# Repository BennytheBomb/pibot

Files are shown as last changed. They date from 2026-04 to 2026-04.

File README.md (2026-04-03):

# PiBot — Open Source Autonomous Indoor Robot

> A fully autonomous indoor mobile robot built on Raspberry Pi 5, featuring SLAM-based mapping, Nav2 autonomous navigation, and a complete ROS 2 software stack. Built from scratch as a learning project and open sourced for the robotics community.

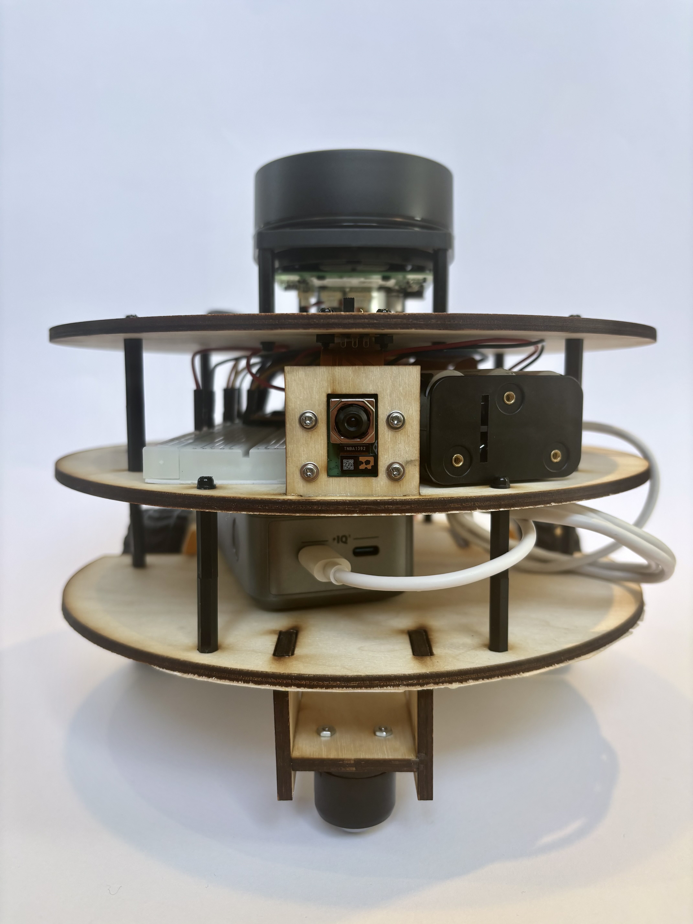
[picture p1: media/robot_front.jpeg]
PiBot Robot


---

## Table of Contents

1. [Project Overview](#1-project-overview)
2. [Design Decisions](#2-design-decisions)
3. [Bill of Materials](#3-bill-of-materials)
4. [Chassis Design and Assembly](#4-chassis-design-and-assembly)
5. [Wiring and Electronics](#5-wiring-and-electronics)
6. [Ubuntu 24.04 Setup](#6-ubuntu-2404-setup)
7. [libcamera Build from Source](#7-libcamera-build-from-source)
8. [ROS 2 Jazzy Setup](#8-ros-2-jazzy-setup)
9. [PlatformIO and Pico Firmware](#9-platformio-and-pico-firmware)
10. [ROS 2 Workspace Setup](#10-ros-2-workspace-setup)
11. [Development Tools](#11-development-tools)
12. [Calibration](#12-calibration)
13. [Running the Robot](#13-running-the-robot)
14. [SLAM Mapping](#14-slam-mapping)
15. [Autonomous Navigation with Nav2](#15-autonomous-navigation-with-nav2)
16. [Troubleshooting](#16-troubleshooting)
17. [Known Issues and Lessons Learned](#17-known-issues-and-lessons-learned)
18. [Future Work](#18-future-work)
19. [Resources](#19-resources)

---

## 1. Project Overview

PiBot is a fully autonomous indoor mobile robot built from scratch using off-the-shelf components and open source software. The project covers the complete robotics stack:

- **Hardware:** Custom laser-cut plywood chassis, differential drive with encoder motors, RPLIDAR A1, GY-87 IMU
- **Firmware:** PID velocity control on Raspberry Pi Pico 2W
- **Middleware:** ROS 2 Jazzy on Raspberry Pi 5 running Ubuntu 24.04
- **Perception:** RPLIDAR A1M8 for 2D lidar scanning
- **Localization:** AMCL on a pre-built map
- **Mapping:** SLAM Toolbox for online async mapping
- **Navigation:** Nav2 with Regulated Pure Pursuit controller
- **Sensor Fusion:** robot_localization EKF fusing wheel odometry and IMU

The project started as a ball-following robot following the [Digikey ROS 2 Tutorial Series](https://www.youtube.com/watch?v=mjrxf8EFSb8&list=PLEBQazB0HUySWueUF2zNyrA8LSX3rDvE7) and evolved into the full autonomous navigation stack in `pibot_base`.

> **Note:** The Raspberry Pi Camera Module 3 and `camera_ros` driver are included in the repository for optional use (e.g. computer vision, object detection) but are **not required** for replicating the navigation robot. The core navigation stack uses only the RPLIDAR and IMU.

**Navigation accuracy:** ~±10cm position, ~±30° heading at goal.
**Power bank runtime:** ~1 hour on the Anker Prime 12,000mAh.
**Motor battery runtime:** Varies — NiMH batteries drain faster than expected under load. Keep spare batteries charged.

### Architecture Overview

```mermaid
graph TD
    subgraph Pi5["Raspberry Pi 5 — ROS 2 Jazzy"]
        SB[serial_bridge\nodom + IMU publisher\ncmd_vel subscriber]
        EKF[robot_localization\nEKF sensor fusion]
        SLAM[SLAM Toolbox\nonline async mapping]
        NAV2[Nav2\npath planning + control]
        RSP[robot_state_publisher\nURDF + TF static]
        LIDAR[rplidar_ros\nlidar driver]
    end

    subgraph Pico["Raspberry Pi Pico 2W — bare metal"]
        PID[PID velocity control\n100Hz]
        ENC[Encoder ISR\nCHANGE interrupt]
        IMU_FW[IMU reader\nMPU6050 I2C]
    end

    subgraph Hardware["Hardware"]
        TB[TB6612FNG\nmotor driver]
        MOTORS[TT Motors ×2\nwith encoder]
        GY87[GY-87 IMU]
        RPLIDAR_HW[RPLIDAR A1M8]
    end

    Pi5 -- USB Serial\nleft_vel,right_vel --> Pico
    Pico -- USB Serial\nticks + IMU 50Hz --> Pi5

    PID --> TB --> MOTORS
    MOTORS --> ENC
    GY87 --> IMU_FW
    RPLIDAR_HW --> LIDAR

    SB --> EKF
    EKF --> SLAM
    EKF --> NAV2
    LIDAR --> SLAM
    LIDAR --> NAV2
    RSP --> SLAM
```

### Serial Communication Protocol

```
Pi 5 → Pico:  "left_vel,right_vel\n"       (float m/s, sent on cmd_vel)
Pico → Pi 5:  "lt,rt,ax,ay,az,gx,gy,gz\n" (ticks + IMU, 50Hz)
```

---

## 2. Design Decisions

### 2.1 Raspberry Pi 5 as Main Computer

The Pi 5 has sufficient CPU performance to run ROS 2, SLAM Toolbox, and Nav2 simultaneously, native USB 3.0 for reliable RPLIDAR connection, Ubuntu 24.04 support with ROS 2 Jazzy, and wide community support.

**Tradeoff:** The Pi 5 requires more power than alternatives (~5A peak), requiring a dedicated power bank.

### 2.2 Raspberry Pi Pico 2W as Hardware Bridge

Chosen following the Digikey ROS 2 Tutorial Series recommendation:

- **Real-time control:** Linux on the Pi 5 has non-deterministic scheduling. PID at 100Hz requires precise timing — the Pico runs bare metal
- **GPIO protection:** All motor and encoder connections stay on the Pico, protecting the Pi 5
- **Separation of concerns:** Clean split between high-level navigation (Pi 5) and low-level control (Pico)
- **Price:** Very cheap — the 2W variant was chosen over standard Pico because the price difference is minimal and WiFi/Bluetooth may be useful for future projects

**Known annoyance:** When firmware crashes, you cannot simply reflash. You must unplug the USB cable, hold BOOTSEL, reinsert USB (Pico appears as `RPI-RP2` drive), then flash again. This is worth knowing before you start.

### 2.3 PlatformIO over Arduino IDE

- **Remote flashing:** Compile and flash from Pi 5 over SSH — no separate computer needed
- **VS Code integration:** Same editor used for all ROS 2 development
- **Reproducible builds:** Libraries declared in `platformio.ini`
- **CLI:** `pio run --target upload` from any terminal

### 2.4 Three-Platform Laser-Cut Chassis

Before designing, all component measurements were gathered from technical drawings, datasheets, and physical measurement with calipers. Components were then laid out in Affinity Designer (top and side view) at correct scale before cutting anything.

Three circular platforms with M3 Abstandsbolzen (hex standoffs) were chosen:
- **Bottom:** Motor support structure, ball caster mount, power bank
- **Middle:** Pi 5, breadboard, Pico, motor driver, IMU
- **Top:** Lidar, camera

**Why circular:** Optimal for Nav2 — equal turning radius in all directions, simplest costmap footprint.

**Why laser-cut plywood:** Fast to iterate, precise holes, cheap, widely available at makerspaces.

**Why standoffs over spacers:** Laser-cutting spacers from acrylic would be brittle under screw torque. M3 brass standoffs are rigid, reusable, and cheap.

**Motor layout:** An equilateral triangle was designed to position motors and ball caster with equal spacing — theoretically optimal for turning. In practice the wheels stick out slightly more than planned due to not fully accounting for wheel width during layout. No operational impact but worth planning carefully.

**Kerf note:** The laser cutter removes a small amount of material (kerf) at each cut — this was not accounted for in the design. Joints that were intended to be tight fits were slightly loose as a result. Wood glue was used to compensate and produced a very stable result.

### 2.5 Wood Glue for Support Structure

The T-shaped support structure connecting motors and ball caster to the bottom platform is assembled using wood glue in addition to screws. The glue compensates for kerf tolerances and significantly increases rigidity.

### 2.6 RPLIDAR A1 over Other Lidars

Cheapest available 360° lidar at Berrybase.de (~€90). Praised by the Digikey channel for price-to-performance. 12m range and 5-8Hz scan rate are adequate for slow indoor navigation.

### 2.7 Anker Prime Power Bank

The Anker Prime 12,000mAh 130W powers the Pi 5 and all connected electronics (cooling fan, lidar, encoders, Pico). Provides ~1 hour runtime. Minimum 5V/5A output is required for stable Pi 5 operation.

### 2.8 NiMH Batteries for Motors

6× AA NiMH 1.2V 2800mAh batteries power the motors. NiMH chosen over alkaline for rechargeability and consistent voltage under load. Runtime is shorter than expected under heavy use — keep spare sets charged.

### 2.9 camera_ros for Camera Integration (Optional)

The `camera_ros` package by Christian Rauch is included in the repository for optional Camera Module 3 integration. It handles the libcamera stack natively as a ROS 2 node, publishing standard `sensor_msgs/Image` topics. This is useful for future extensions like object detection or visual servoing, but is **not required** for the core navigation stack. If you don't plan to use a camera, you can skip the libcamera build (Section 7) and ignore the `camera_ros` submodule.

---

## 3. Bill of Materials

### Electronics (Berrybase.de)

| Component | Description | Qty | Unit Price | Total |
|---|---|-----|---|---|
| Raspberry Pi 5 | 8GB RAM, main compute | 1 | €127.90 | €127.90 |
| Raspberry Pi Pico 2W | RP2350 + WiFi + BT, with headers | 1 | €8.50 | €8.50 |
| _Raspberry Pi Camera Module 3 (optional)_ | 12MP, IMX708 sensor | 1 | €28.90 | €28.90 |
| Raspberry Pi Active Cooler | Fan for Pi 5 | 1 | €5.90 | €5.90 |
| _Raspberry Pi 27W USB-C PSU (optional)_ | For desktop use / initial setup | 1 | €12.40 | €12.40 |
| Seeed RPLIDAR A1M8 | 360° 2D laser scanner, 12m range | 1 | €89.90 | €89.90 |
| DFRobot TT Motor with Encoder | 160RPM, 120:1, quadrature encoder | 2 | €7.30 | €14.60 |
| SparkFun TB6612FNG | Dual motor driver with headers | 1 | €15.90 | €15.90 |
| GY-87 IMU | MPU-6050 + HMC5883L + BMP180 | 1 | €12.80 | €12.80 |
| Pololu Ball Caster | 0.75 inch metal ball, adjustable height | 1 | €4.50 | €4.50 |
| Wheels 65mm | Rubber tyre, 2 pieces | 1 set | €4.60 | €4.60 |
| Breadboard 830 contacts | Main wiring board | 1 | €1.90 | €1.90 |
| Jumper Wire Set | F-F / M-M / F-M, 20cm | 1 | €4.90 | €4.90 |
| Battery Holder 6× AA | With 150mm cable | 2 | €0.75 | €1.50 |
| **Electronics Total** | | | | **~€333** |

> Prices from Berrybase.de, early 2026.

### Additional Components

| Component | Description | Notes |
|---|---|---|
| Anker Prime Power Bank | 12,000mAh, 130W, USB-C | Powers Pi 5 + all electronics. Minimum 5V/5A required |
| AA NiMH Batteries (6×) | 1.2V, 2800mAh per cell | Motor power. Keep spare sets charged |
| Slide switch (SPST) | Two-position slide switch | Battery power cutoff, mounted with M2.5 screws |
| 4mm birch plywood | ~30×30cm sheet | Laser cut chassis. Available at hardware stores |
| Wood glue | Standard PVA wood glue | For chassis support structure assembly |
| M2/M2.5/M3 assorted screw kit | 900-piece set | See note below |
| M3 × 30mm screws (extra) | Motor mounting | Not included in standard kits — source separately |
| M2.5 × 40mm hex standoffs | Platform spacing | 6x 40mm standoffs or 12x 20mm standoffs (screwed together) |

**Screw sizes used:**
- M2.5 × 8mm, 12mm, 20mm — Pi 5 mounting
- M2 × 6mm, 8mm, 10mm, 12mm — Camera Module 3 and small components
- M3 × 8mm, 12mm, 16mm, 20mm — General chassis mounting
- M3 × 30mm — Motor mounting (source separately from hardware store or makerspace)

**Estimated total cost: ~€380–420** including power bank, batteries, screws, plywood, and glue.

---

## 4. Chassis Design and Assembly

### 4.1 Design Process

All component measurements were gathered before designing:
- Technical drawings: Pi 5, Camera Module 3, Pico 2W datasheets
- Product descriptions: motors, lidar, ball caster
- Physical calipers: wheel diameter, motor body, connectors

Components were laid out in Affinity Designer in both top view and side view at correct scale before cutting. This step is essential — it reveals conflicts and tight fits before wasting material.

### 4.2 Platform Stack

```
Top platform    z=138.7mm   Lidar (on standoffs), camera (front)
      │
      │  40mm M3 standoffs (×3)
      │
Mid platform    z=94.7mm    Pi 5, breadboard, Pico, motor driver, IMU
      │
      │  40mm M3 standoffs (×3)
      │
Bot platform    z=50.7mm    Anker power bank
      │
T-support structure         Motors (horizontal bar) + ball caster (vertical bar)
      │
Ground          z=0mm       Wheels (rear) + ball caster (front)
```

### 4.3 Key Dimensions

| Measurement | Value |
|---|---|
| Platform diameter | 210mm |
| Platform thickness | 4mm |
| Gap between platforms | 40mm |
| Wheel center x-offset | -55.3mm from center (rear) |
| Wheel center y-offset | ±86.5mm from center |
| Ball caster x-offset | +86.8mm from center (front) |
| Wheelbase physical | 173mm center-to-center |
| Wheelbase effective (calibrated) | 159mm |
| Lidar x-offset | +6.9mm (slightly forward) |
| Ground clearance | 27mm |
| Wheel radius | 32.5mm |

### 4.4 Laser Cutting

**Software:** Affinity Designer — export as DXF for laser cutter.

**Files in `cad/`:**
- `chassis.af` — source file
- `chassis.dxf` — laser cutter export

**Kerf:** The laser removes a small amount of material at each cut. This was not accounted for in the original design — joints designed to be tight fits were slightly loose as a result. **Compensate with wood glue** which produces a strong and stable result. Alternatively, offset your cut lines outward by your laser's kerf width (typically 0.1–0.2mm for plywood).

**Tips:**
- Use hairline stroke (0.001mm) for cut lines
- Cut test holes before the full platforms to verify motor shaft and standoff diameters
- Label each platform before removing from the cutter sheet

### 4.5 Support Structure Assembly

The T-shaped support structure that holds the motors and ball caster is assembled with:
1. **Screws** (M3 × 30mm for motors)
2. **Wood glue** at all plywood-to-plywood joints

Apply wood glue to mating surfaces, clamp or hold for 30 minutes, allow 24 hours full cure before loading. The combination of glue and screws produces a very rigid structure despite the loose kerf fits.

### 4.6 Full Assembly Order

1. Dry-fit all laser-cut parts to verify fit before gluing
2. Glue and screw T-support structure together — allow to cure
3. Mount motors to horizontal bar of T-support (M3 × 30mm screws)
4. Attach T-support to underside of bottom platform
5. Mount ball caster to front vertical bar of T-support
6. Install wheels on motor output shafts
7. Install M2.5 × 40mm standoffs between platforms (3 per gap)
8. Mount power bank to bottom platform
9. Mount Pi 5 to middle platform (M2.5 standoffs)
10. Peel off breadboard bottom and stick glued side to middle platform
11. Mount Pico, motor driver on breadboard
12. Mount IMU — note orientation for software correction
13. Mount lidar on standoffs on top platform
14. Mount camera at front of top platform
15. Route and connect all wiring (Section 5)
16. Mount slide switch accessibly on the top cutout

---

## 5. Wiring and Electronics

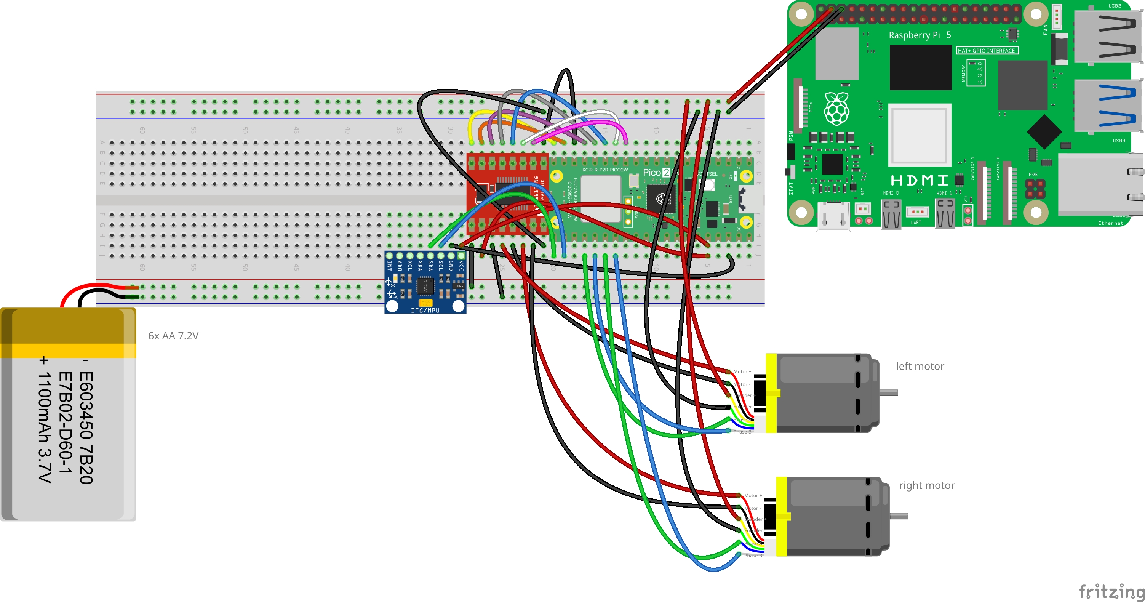
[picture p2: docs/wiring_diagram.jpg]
Wiring Diagram


### 5.1 Power Architecture

Two separate power rails isolate motor noise from computer electronics:

```
AA NiMH Batteries (6×, ~7.2V)
    │
    ├── Slide switch
    └── TB6612FNG VM (motor power)

Anker Prime Power Bank (5V USB-C)
    │
    └── Raspberry Pi 5
        └── Pi 5 GPIO 5V pin → Encoder VCC

Common GND: Pi 5 GND + Pico GND + Battery − + TB6612FNG GND + Encoder GND + IMU GND
            all connected to breadboard GND rail
```

### 5.2 Pico GPIO Pin Assignments

| GPIO | Function |
|---|---|
| 9 | PWMB — right motor PWM |
| 10 | BIN2 — right motor direction |
| 11 | BIN1 — right motor direction |
| 12 | STBY — motor driver standby |
| 13 | AIN1 — left motor direction |
| 14 | AIN2 — left motor direction |
| 15 | PWMA — left motor PWM |
| 16 | SDA — IMU I2C data (I2C0) |
| 17 | SCL — IMU I2C clock (I2C0) |
| 18 | ENC_LEFT_A |
| 19 | ENC_LEFT_B |
| 20 | ENC_RIGHT_A |
| 21 | ENC_RIGHT_B |

### 5.3 TB6612FNG Connections

| TB6612FNG Pin | Connected To |
|---|---|
| PWMA | Pico GPIO 15 |
| AIN1 | Pico GPIO 13 |
| AIN2 | Pico GPIO 14 |
| PWMB | Pico GPIO 9 |
| BIN1 | Pico GPIO 11 |
| BIN2 | Pico GPIO 10 |
| STBY | Pico GPIO 12 |
| VM | Battery + (~7.2V) |
| VCC | Pico 3.3V |
| GND | Common ground |
| A01, A02 | Left motor |
| B01, B02 | Right motor |

### 5.4 Encoder Connections

> ⚠️ **Voltage level warning:** The DFRobot TT encoders require 4.5–7.5V on VCC and output signals at that voltage. The Raspberry Pi Pico 2W GPIO pins are rated for 3.3V maximum. Connecting 5V signals directly to Pico GPIO pins is technically out of spec and may cause long-term damage.
>
> The correct solution is a **logic level converter** (bi-directional, 3.3V↔5V) on the A and B signal lines. These cost ~€1–2 on AliExpress and are the recommended approach.
>
> During development, direct 5V→Pico GPIO connection was used after voltage dividers caused severe pulse loss (>90% of encoder pulses were missed). Direct connection worked reliably for this project but proceed at your own risk. If you experience erratic encoder readings or Pico failures, a logic level converter is the proper fix.

| Encoder Pin | Connected To |
|---|---|
| VCC | Pi 5 5V (GPIO header pin 2 or 4) |
| GND | Common ground |
| A phase | Logic level converter → Pico GPIO (18=left, 20=right) |
| B phase | Logic level converter → Pico GPIO (19=left, 21=right) |

**Why Pi 5 5V and not Pico 5V:** The Pico does not have a 5V output pin. The Pi 5 GPIO header provides a stable 5V rail from the USB-C power supply.

### 5.5 GY-87 IMU Connections

Operates at 3.3V — directly compatible with Pico. GPIO 16/17 are I2C0 — use `Wire` (not `Wire1`) in firmware.

| GY-87 Pin | Connected To |
|---|---|
| VCC / 3.3V | Pico 3.3V |
| GND | Common ground |
| SDA | Pico GPIO 16 |
| SCL | Pico GPIO 17 |
| FSYNC, INTA, DRDY | Not connected |

I2C addresses: MPU-6050 = 0x68, HMC5883L = 0x1E, BMP180 = 0x77.

**Mounting:** The GY-87 is mounted backwards (Y axis points toward robot rear). This is corrected in software — see Section 10.6.

### 5.6 RPLIDAR Setup

Connects via USB to Pi 5. Create stable udev symlink:

```bash
sudo tee /etc/udev/rules.d/99-rplidar.rules << 'EOF'
KERNEL=="ttyUSB*", ATTRS{idVendor}=="10c4", ATTRS{idProduct}=="ea60", MODE="0666", GROUP="dialout", SYMLINK+="rplidar"
EOF
sudo udevadm control --reload-rules && sudo udevadm trigger
```

### 5.7 Slide Switch

Wire in series on battery positive line:
```
Battery + → Slide switch → TB6612FNG VM
Battery − → Common ground
```

Mount with M2.5 screws through chassis wall.

---

## 6. Ubuntu 24.04 Setup

### 6.1 Installation

Download Ubuntu 24.04 LTS for Raspberry Pi from: https://ubuntu.com/download/raspberry-pi

Flash to SD card using Raspberry Pi Imager. Ubuntu Server (headless) is recommended — smaller footprint, cooler operation. All development is done remotely over SSH.

### 6.2 Initial Configuration

```bash
sudo apt update && sudo apt upgrade -y

sudo apt install -y \
    git curl wget vim tmux \
    python3-pip python3-serial \
    net-tools usbutils

# Serial port access
sudo usermod -a -G dialout $USER
```

### 6.3 SSH Setup

```bash
# Enable passwordless SSH from your development machine
ssh-copy-id your-user@pibot.local

# Add to ~/.ssh/config on your Mac/PC
Host pibot
    HostName pibot.local
    User your-user
    ForwardX11 yes
```

### 6.4 VS Code Remote Development

Install the **Remote - SSH** extension in VS Code. Connect to the Pi 5 and open `~/pibot` as your workspace. All development — firmware, ROS 2 packages, configuration files — can be done remotely with full IDE features.

---

## 7. libcamera Build from Source

> **Optional:** This section is only needed if you want to use the Raspberry Pi Camera Module 3. The core navigation stack does not require a camera.

The Pi 5 with Camera Module 3 (IMX708 sensor) on Ubuntu 24.04 requires the Raspberry Pi fork of libcamera. The standard Ubuntu package does not support this sensor.

> This guide follows: https://dev.to/minindu_pasan_8f0e03c1063/how-to-setup-raspberry-pi-camera-module-3-on-ubuntu-2404-4pme

### 7.1 Install Build Dependencies

```bash
sudo apt install -y \
    meson ninja-build pkg-config \
    libgnutls28-dev openssl libtiff-dev \
    pybind11-dev qtbase5-dev libqt5core5a \
    libboost-dev libglib2.0-dev \
    libgstreamer-plugins-base1.0-dev \
    python3-yaml python3-ply python3-jinja2
```

### 7.2 Clone and Build

```bash
cd ~
git clone https://github.com/raspberrypi/libcamera.git
cd libcamera

meson setup build \
    -Dpipelines=rpi/pisp \
    -Dipas=rpi/pisp \
    -Dv4l2=true \
    -Dpycamera=enabled

ninja -C build
sudo ninja -C build install
```

### 7.3 Fix Python Bindings Path

```bash
echo "/usr/local/lib/python3/dist-packages" | \
    sudo tee /usr/local/lib/python3.12/dist-packages/libcamera.pth
```

### 7.4 Verify

```bash
cam -l   # should list: imx708 camera
python3 -c "import libcamera; print('OK')"
```

### 7.5 libcamera in the ROS 2 Workspace

The `camera_ros` package requires the libcamera source to be present in the workspace for building. This repository includes libcamera as a git submodule at `pibot_ws/src/libcamera`.

> **Note:** The libcamera submodule is configured with `shallow = true` in `.gitmodules` to avoid downloading the full repository history. This significantly reduces clone size.

If you cloned without submodules, initialize them manually:

```bash
cd ~/pibot
git submodule update --init --depth 1
```

The workspace build will compile libcamera alongside the ROS 2 packages using `colcon-meson`.

---

## 8. ROS 2 Jazzy Setup

### 8.1 Install ROS 2 Jazzy

```bash
sudo apt install -y software-properties-common
sudo add-apt-repository universe
sudo apt update && sudo apt install -y curl

sudo curl -sSL https://raw.githubusercontent.com/ros/rosdistro/master/ros.key \
    -o /usr/share/keyrings/ros-archive-keyring.gpg

echo "deb [arch=$(dpkg --print-architecture) signed-by=/usr/share/keyrings/ros-archive-keyring.gpg] \
    http://packages.ros.org/ros2/ubuntu $(. /etc/os-release && echo $UBUNTU_CODENAME) main" | \
    sudo tee /etc/apt/sources.list.d/ros2.list > /dev/null

sudo apt update
sudo apt install -y ros-jazzy-desktop
```

### 8.2 Environment Setup

```bash
echo "source /opt/ros/jazzy/setup.bash" >> ~/.bashrc
source ~/.bashrc
```

### 8.3 Install Required Packages

```bash
sudo apt install -y \
    ros-jazzy-robot-localization \
    ros-jazzy-slam-toolbox \
    ros-jazzy-navigation2 \
    ros-jazzy-nav2-bringup \
    ros-jazzy-rplidar-ros \
    ros-jazzy-robot-state-publisher \
    ros-jazzy-joint-state-publisher \
    ros-jazzy-tf2-ros \
    ros-jazzy-tf2-tools \
    ros-jazzy-cv-bridge \
    ros-jazzy-foxglove-bridge \
    ros-jazzy-teleop-twist-keyboard \
    ros-jazzy-nav2-map-server \
    python3-colcon-common-extensions \
    python3-colcon-meson \
    python3-rosdep

# Python serial library — required by serial_bridge node
sudo pip3 install pyserial --break-system-packages
```

### 8.4 Initialize rosdep

```bash
sudo rosdep init
rosdep update
```

### 8.5 udev Rules

```bash
# RPLIDAR stable symlink
sudo tee /etc/udev/rules.d/99-rplidar.rules << 'EOF'
KERNEL=="ttyUSB*", ATTRS{idVendor}=="10c4", ATTRS{idProduct}=="ea60", MODE="0666", GROUP="dialout", SYMLINK+="rplidar"
EOF

# Pico 2W upload permissions
sudo tee /etc/udev/rules.d/99-pico.rules << 'EOF'
SUBSYSTEMS=="usb", ATTRS{idVendor}=="2e8a", MODE="0666"
EOF

sudo udevadm control --reload-rules && sudo udevadm trigger
```

---

## 9. PlatformIO and Pico Firmware

### 9.1 Install PlatformIO

```bash
sudo pip3 install platformio --break-system-packages
```

### 9.2 Project Structure

```
pico_firmware/
├── platformio.ini
└── src/
    └── main.cpp
```

**platformio.ini:**
```ini
[env:rpipico2w]
platform = https://github.com/maxgerhardt/platform-raspberrypi.git
board = rpipico2w
framework = arduino
board_build.core = earlephilhower
upload_port = /dev/ttyACM0
monitor_port = /dev/ttyACM0
monitor_speed = 115200
lib_deps =
    https://github.com/sparkfun/SparkFun_TB6612FNG_Arduino_Library.git
    adafruit/Adafruit MPU6050@^2.2.6
    adafruit/Adafruit Unified Sensor@^1.1.14
```

### 9.3 Build and Flash

```bash
cd ~/pibot/pico_firmware

pio run                     # build only
pio run --target upload     # build and flash
pio device monitor          # open serial monitor
```

> **If upload fails:** Put Pico into bootloader mode manually — unplug USB, hold BOOTSEL button, replug USB. The Pico appears as `RPI-RP2` drive. Run `pio run --target upload` again.

### 9.4 Firmware Design

**PID in ticks-per-interval units:**

The key design choice is running PID in ticks-per-10ms-interval rather than m/s. This matches the DFRobot encoder sample code approach and gives small, intuitive gains:

```cpp
// Convert m/s target to ticks per 10ms interval
float target_ticks = target_vel * (10.0f / 1000.0f) / DIST_PER_TICK;
// At 0.15 m/s: ~15.7 ticks per interval
// Kp=1.5: 1 tick error → 1.5 PWM correction
```

**Robot constants:**
```cpp
const float WHEEL_DIAMETER_M = 0.065f;
const float TICKS_PER_REV    = 2140.0f;  // empirically calibrated
const float DIST_PER_TICK    = PI * WHEEL_DIAMETER_M / TICKS_PER_REV;
const float MAX_WHEEL_VEL    = (160.0f / 60.0f) * PI * WHEEL_DIAMETER_M;
```

**PID gains (tune for your motors):**
```cpp
float KP = 1.5f;
float KI = 0.8f;
float KD = 0.05f;
const float MAX_INTEGRAL = 50.0f;  // anti-windup clamp
```

**Debug mode:** `#define DEBUG 1` prints target ticks, actual ticks, and PWM to serial monitor — useful for tuning. Set to 0 for normal operation.

---

## 10. ROS 2 Workspace Setup

### 10.1 Cloning and Building

```bash
git clone --recurse-submodules git@github.com:BennytheBomb/pibot.git
cd pibot/pibot_ws

rosdep install -y --from-paths src --ignore-src \
    --rosdistro jazzy --skip-keys=libcamera

colcon build
source install/setup.bash

echo "source ~/pibot/pibot_ws/install/setup.bash" >> ~/.bashrc
```

> If you already cloned without `--recurse-submodules`, run `git submodule update --init --depth 1` before building.

### 10.2 Package Overview

| Package | Purpose |
|---|---|
| `pibot_base` | Main package: serial bridge, URDF, EKF, SLAM, Nav2, launch files |
| `camera_ros` | Camera Module 3 ROS 2 driver — optional (submodule) |
| `libcamera` | Raspberry Pi libcamera fork — optional (submodule, shallow clone) |

### 10.3 Key Topics

| Topic | Type | Description |
|---|---|---|
| `/odom` | `nav_msgs/Odometry` | Raw wheel encoder odometry |
| `/imu/data_raw` | `sensor_msgs/Imu` | Raw IMU (corrected for mounting) |
| `/odometry/filtered` | `nav_msgs/Odometry` | EKF-fused odometry |
| `/scan` | `sensor_msgs/LaserScan` | RPLIDAR scan |
| `/map` | `nav_msgs/OccupancyGrid` | SLAM occupancy grid |
| `/cmd_vel` | `geometry_msgs/Twist` | Motor velocity commands |
| `/goal_pose` | `geometry_msgs/PoseStamped` | Nav2 navigation goal |
| `/amcl_pose` | `geometry_msgs/PoseStamped` | AMCL robot pose estimate |

### 10.4 TF Tree

```
map
 └── odom  (AMCL correction)
      └── base_link  (serial_bridge / EKF)
           ├── lidar_link   (rpy="0 0 π" — mounted backwards)
           ├── imu_link     (rpy="0 0 π" — mounted backwards)
           ├── camera_link
           ├── left_wheel   (continuous joint)
           ├── right_wheel  (continuous joint)
           ├── ball_caster
           ├── bottom_platform
           ├── mid_platform
           └── top_platform
```

### 10.5 URDF Link Positions

Relative to `base_link` (ground level, robot center). REP-103: x=forward, y=left, z=up.

| Link | x (m) | y (m) | z (m) | Notes |
|---|---|---|---|---|
| bottom_platform | 0.0 | 0.0 | 0.0507 | |
| mid_platform | 0.0 | 0.0 | 0.0947 | |
| top_platform | 0.0 | 0.0 | 0.1387 | |
| left_wheel | -0.0553 | +0.0865 | 0.0325 | |
| right_wheel | -0.0553 | -0.0865 | 0.0325 | |
| ball_caster | +0.0868 | 0.0 | 0.010325 | |
| lidar_link | +0.0069 | 0.0 | 0.16785 | rpy="0 0 3.14159" |
| camera_link | +0.100 | 0.0 | 0.1151 | |
| imu_link | +0.004 | -0.004 | 0.1136 | rpy="0 0 3.14159" |

### 10.6 IMU Frame Correction

GY-87 mounted backwards — applied in `serial_bridge.py`:

```python
# robot_x = -imu_y,  robot_y = -imu_x,  robot_z = imu_z
msg.linear_acceleration.x = -imu_ay
msg.linear_acceleration.y = -imu_ax
msg.linear_acceleration.z =  imu_az
msg.angular_velocity.x = -imu_gy
msg.angular_velocity.y = -imu_gx
msg.angular_velocity.z =  imu_gz
```

Verify: rotating left gives positive `angular_velocity.z`. Stationary: `linear_acceleration.z ≈ +9.81`.

### 10.7 EKF Configuration

Fuses `/odom` (x, y, yaw, vx, vyaw) with `/imu/data_raw` (vyaw/gz only). Accelerometer excluded — too noisy for ground robot position estimation.

```yaml
frequency: 50.0
two_d_mode: true    # ignore z, roll, pitch
world_frame: odom   # map frame correction added by Nav2 AMCL
```

---

## 11. Development Tools

### 11.1 tmux — Terminal Management

Running 7-8 ROS 2 nodes simultaneously over SSH requires good terminal management. Install and configure tmux:

```bash
# tmux is installed in Section 6.2 initial setup
echo "set -g mouse on" >> ~/.tmux.conf  # enable drag-to-resize and click-to-focus
tmux source ~/.tmux.conf
```

**Essential shortcuts:**
```
Ctrl+B "      split pane horizontally
Ctrl+B %      split pane vertically
Ctrl+B arrows navigate between panes
Ctrl+B z      zoom pane fullscreen (press again to unzoom)
Ctrl+B d      detach (session keeps running in background)

tmux new -s robot       create named session
tmux attach -t robot    reattach to session
tmux kill-session -t robot  kill all nodes and session
```

Drag pane borders to resize after enabling mouse support.

### 11.2 Foxglove Studio — Visualization

Runs in the browser or as a desktop app, connects over WiFi — no display needed on the Pi:

```bash
# On Pi 5
ros2 launch foxglove_bridge foxglove_bridge_launch.xml
```

Connect: Foxglove desktop app → Open Connection → **Foxglove WebSocket** → `ws://[pi-ip]:8765`

> Use the **desktop app** rather than browser — browsers may block non-secure WebSocket connections from HTTPS pages.

**Useful panels:**
- **3D** — map, scan, robot model, TF
- **Map** — occupancy grid view
- **Plot** — odometry x/y over time for debugging
- **Publish** — send goal poses to Nav2
- **Raw Messages** — inspect any topic

### 11.3 VS Code Extensions

- Remote - SSH
- ROS (ms-iot.vscode-ros)
- C/C++ (for firmware development)
- Python
- PlatformIO IDE

### 11.4 Useful ROS 2 Commands

```bash
ros2 topic list                            # all active topics
ros2 topic echo /odom                      # stream topic messages
ros2 topic hz /scan                        # check publish rate
ros2 node list                             # active nodes
ros2 node info /serial_bridge              # node connections
ros2 run tf2_tools view_frames             # generate TF tree PDF
ros2 run tf2_ros tf2_echo odom lidar_link  # check specific transform
ros2 lifecycle get /slam_toolbox           # SLAM Toolbox state
```

---

## 12. Calibration

These calibrations must be performed after assembly. Pre-calibrated values in the firmware and serial bridge are specific to the motors used in this build — your motors will likely differ.

> **Testing approach:** Because opening a new serial connection resets the Pico, use separate scripts for before/after readings rather than trying to send commands and read results in a single script.

### 12.1 Motor Direction

```bash
python3 -c "
import serial, time
s = serial.Serial('/dev/ttyACM0', 115200, timeout=2)
time.sleep(3)
s.write(b'0.1,0.1\n')
time.sleep(3)
s.write(b'0.0,0.0\n')
s.close()
"
```

Both wheels should spin forward. If a motor spins backward, swap its output wires on the TB6612FNG (A01↔A02 or B01↔B02).

### 12.2 Encoder Direction

Spin each wheel by hand and verify ticks change correctly:

```bash
python3 -c "
import serial, time
s = serial.Serial('/dev/ttyACM0', 115200, timeout=2)
time.sleep(3)
prev = None
for _ in range(60):
    line = s.readline().decode('utf-8', errors='ignore').strip()
    parts = line.split(',')
    if len(parts) == 8:
        lt, rt = int(parts[0]), int(parts[1])
        if prev != (lt, rt):
            print(f'L:{lt:>8} R:{rt:>8}')
            prev = (lt, rt)
s.close()
"
```

Spin forward → counts increase. Spin backward → counts decrease.

### 12.3 TICKS_PER_REV Calibration

**Step 1 — Read start ticks:**
```bash
python3 -c "
import serial, time
s = serial.Serial('/dev/ttyACM0', 115200, timeout=2)
time.sleep(3)
for _ in range(5): s.readline()
for _ in range(3):
    line = s.readline().decode('utf-8', errors='ignore').strip()
    parts = line.split(',')
    if len(parts) == 8: print(f'L:{parts[0]} R:{parts[1]}')
s.close()
"
```

**Step 2 — Drive forward and measure distance:**
```bash
python3 -c "
import serial, time
s = serial.Serial('/dev/ttyACM0', 115200, timeout=2)
time.sleep(3)
s.write(b'0.15,0.15\n')
time.sleep(4)
s.write(b'0.0,0.0\n')
s.close()
"
```

Mark start and end positions with tape. Measure actual distance.

**Step 3 — Read end ticks** (same script as Step 1).

**Calculate:**
```python
import math
delta = ((end_l - start_l) + (end_r - start_r)) / 2
actual_m = 0.335  # replace with your measurement
ticks_per_rev = delta / (actual_m / (math.pi * 0.065))
print(f"TICKS_PER_REV = {ticks_per_rev:.0f}")
```

**Why not 960:** `CHANGE` mode interrupts count both rising and falling edges of the A phase, doubling the nominal 960. Empirical calibration gave ~2140 for these specific motors. Always calibrate.

Update in **both** files:
- `pico_firmware/src/main.cpp`: `const float TICKS_PER_REV = XXXX.0f;`
- `pibot_ws/src/pibot_base/pibot_base/serial_bridge.py`: `TICKS_PER_REV = XXXX`

### 12.4 Wheelbase Calibration

Mark robot heading on the floor. Rotate approximately 360° in place. Measure actual angle.

```python
import math
DIST_PER_TICK = math.pi * 0.065 / 2140  # use your TICKS_PER_REV
dl = (end_l - start_l) * DIST_PER_TICK
dr = (end_r - start_r) * DIST_PER_TICK
arc = dr - dl
actual_rad = actual_degrees * math.pi / 180
wheelbase = arc / actual_rad
print(f"WHEELBASE_M = {wheelbase:.4f}")
```

Update `WHEELBASE_M` in `serial_bridge.py`. Effective wheelbase is typically less than physical due to wheel slip during turns — this is normal.

### 12.5 PID Tuning

Enable `#define DEBUG 1` in firmware. Observe target vs actual ticks in serial monitor while driving.

1. Set `KI=0, KD=0`. Increase `KP` until velocity tracks promptly without oscillation
2. Add `KI` to remove steady-state error
3. Add small `KD` only if oscillation appears

Starting values: `KP=1.5, KI=0.8, KD=0.05`

---

## 13. Running the Robot

### 13.1 Startup Sequence

```bash
# Terminal 1 — hardware bridge (must be first)
ros2 run pibot_base serial_bridge

# Terminal 2 — EKF sensor fusion
ros2 launch pibot_base ekf.launch.py

# Terminal 3 — robot model and static TF
ros2 launch pibot_base display.launch.py

# Terminal 4 — lidar
ros2 launch pibot_base lidar.launch.py

# Terminal 5 — visualization (recommended)
ros2 launch foxglove_bridge foxglove_bridge_launch.xml
```

### 13.2 Verify

```bash
ros2 topic hz /odom               # ~50 Hz
ros2 topic hz /odometry/filtered  # ~50 Hz
ros2 topic hz /scan               # ~6-7 Hz
ros2 run tf2_ros tf2_echo odom lidar_link  # prints transform immediately
```

### 13.3 Teleop Control

```bash
ros2 run teleop_twist_keyboard teleop_twist_keyboard
```

Press `z` several times to reduce speed to ~0.12 m/s.

**Recommended keys only:**
```
i    forward
,    backward
j    turn left
l    turn right
k    stop — always press before changing direction
```

Avoid diagonal keys (u, o, m, .) — they accumulate velocity in ways that cause unstable motor behavior.

---

## 14. SLAM Mapping

### 14.1 Prepare the Environment

- Clear floor of cables and small obstacles
- Add 2-3 asymmetric landmarks (cardboard boxes) — critical in square rooms where all walls look identical to the lidar
- Consistent lighting helps but is not required for lidar-only SLAM

### 14.2 Start SLAM

```bash
ros2 launch pibot_base slam.launch.py
```

SLAM Toolbox is a lifecycle node on ROS 2 Jazzy. After the node starts, activate it manually:

```bash
# Wait until this shows: unconfigured [1]
ros2 lifecycle get /slam_toolbox

ros2 lifecycle set /slam_toolbox configure
sleep 2
ros2 lifecycle set /slam_toolbox activate

# Verify
ros2 lifecycle get /slam_toolbox    # should show: active [3]
ros2 topic list | grep map          # should show /map
```

### 14.3 Mapping Strategy

Drive at maximum 0.12 m/s:

1. **Perimeter first** — drive along all walls in one continuous loop returning to start. This triggers loop closure and is the most important step
2. **Fill the middle** — S-pattern through the room center
3. **Second perimeter** — repeat for better loop closure quality

**Tips:**
- Gradual arcs rather than sharp in-place turns
- Brief stop at corners before turning
- Return close to start position to trigger loop closure
- Avoid long reverse movements

### 14.4 Monitor Quality in Foxglove

Add `/map` and `/scan` to the 3D panel. Lidar dots should align with black wall lines. If they float away, SLAM has lost tracking — restart.

```bash
ros2 topic hz /map   # ~0.2 Hz updates
```

### 14.5 Save the Map

```bash
ros2 run nav2_map_server map_saver_cli -f ~/map \
    --ros-args -p save_map_timeout:=10.0
```

Creates `~/map.pgm` and `~/map.yaml`.

### 14.6 Example Map

Saved occupancy grid after mapping a room with cardboard box landmarks:

SLAM Map

---

## 15. Autonomous Navigation with Nav2

### 15.1 Start Nav2

```bash
# After serial_bridge, ekf, display, lidar are running:
ros2 launch pibot_base nav2.launch.py
```

Wait for:
```
[lifecycle_manager_navigation]: Managed nodes are active
```

Nav2 running in Foxglove with the SLAM map, robot model, and TF frames:

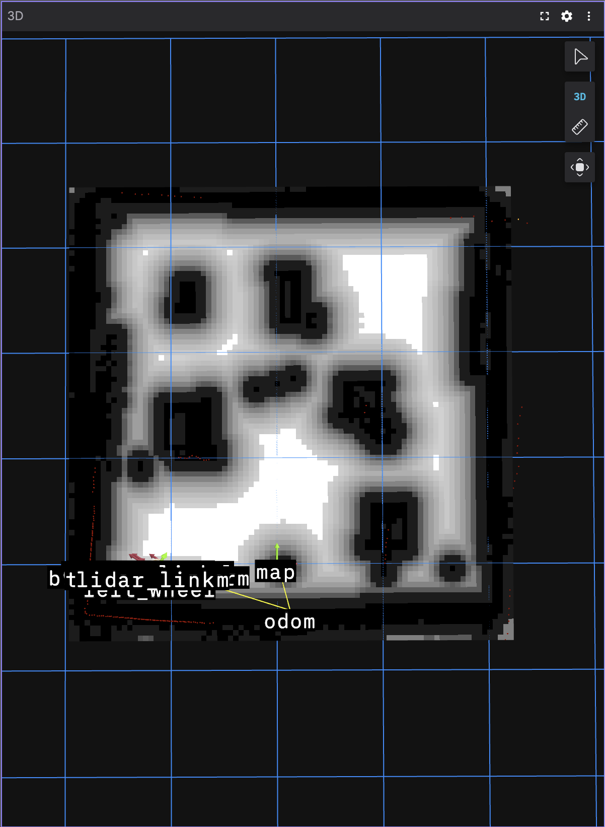
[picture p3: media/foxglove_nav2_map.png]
Foxglove Nav2 Map


### 15.2 Initial Pose

AMCL assumes the robot starts at the map origin (x=0, y=0). Place the robot at the same position as when mapping started, facing the same direction.

### 15.3 Send Navigation Goals

**From Foxglove:** Add a Publish panel → topic `/goal_pose` → type `geometry_msgs/PoseStamped`:

```json
{
  "header": {"frame_id": "map"},
  "pose": {
    "position": {"x": 1.0, "y": 0.0, "z": 0.0},
    "orientation": {"x": 0.0, "y": 0.0, "z": 0.0, "w": 1.0}
  }
}
```

**From command line:**
```bash
ros2 action send_goal /navigate_to_pose nav2_msgs/action/NavigateToPose \
  "{pose: {header: {frame_id: 'map'}, pose: {position: {x: 1.0, y: 0.0, z: 0.0}, orientation: {w: 1.0}}}}"
```

### 15.4 Key Nav2 Parameters

`pibot_base/config/nav2_params.yaml`:

```yaml
robot_radius: 0.115          # half of 210mm platform diameter
inflation_radius: 0.45       # meters — keep robot away from obstacles
desired_linear_vel: 0.15     # m/s
rotate_to_heading_angular_vel: 0.3  # rad/s — keep low to avoid overshoot
xy_goal_tolerance: 0.3       # meters
yaw_goal_tolerance: 0.5      # radians
required_movement_radius: 0.1  # meters per progress check
movement_time_allowance: 15.0  # seconds
```

---

## 16. Troubleshooting

**SLAM not publishing /map**
SLAM Toolbox requires manual lifecycle activation on Jazzy. See Section 14.2.

**Robot drifts while driving straight**
Check encoder calibration (Section 12.2–12.3). Increase PID `KI` to correct steady-state velocity error.

**Encoder pulse loss**
If using voltage dividers on encoder signal lines, remove them. Use a proper logic level converter instead.

**libcamera Python import error**
```bash
echo "/usr/local/lib/python3/dist-packages" | \
    sudo tee /usr/local/lib/python3.12/dist-packages/libcamera.pth
```

**Nav2 bt_navigator fails to start**
Use behavior tree without recovery behaviors in `nav2_params.yaml`:
```yaml
navigate_to_pose:
  default_bt_xml_filename: "/opt/ros/jazzy/share/nav2_bt_navigator/behavior_trees/navigate_w_replanning_only_if_path_becomes_invalid.xml"
```

**Nav2 "Failed to make progress"**
Increase `movement_time_allowance` and decrease `required_movement_radius`.

**Pico cannot be flashed**
Hold BOOTSEL, unplug USB, replug USB. Pico appears as `RPI-RP2` drive. Run `pio run --target upload`.

**RPLIDAR port changes after reconnect**
The udev symlink `/dev/rplidar` handles this automatically. If it doesn't appear: `sudo udevadm trigger`.

---

## 17. Known Issues and Lessons Learned

### Encoder Signal Level Shifting
Voltage dividers (2× 10kΩ) caused >90% pulse loss at motor operating speeds. A proper logic level converter is the correct solution. Direct 5V→3.3V connection worked in practice but is out of spec for the Pico GPIO.

### TICKS_PER_REV Is Not 960
`CHANGE` mode interrupts double the nominal count. Empirical calibration is essential — do not use datasheet values directly.

### SLAM Toolbox Lifecycle Node on Jazzy
Requires manual configure+activate after launch. `use_lifecycle_manager: False` does not prevent this on Jazzy.

### Effective vs Physical Wheelbase
Calibrated effective wheelbase (159mm) is less than physical (173mm) due to wheel slip. Always calibrate empirically.

### Kerf in Laser-Cut Joints
Joints were slightly loose due to unaccounted kerf. Wood glue compensated effectively — the result was very stable. Plan for kerf in your DXF or compensate with glue.

### IMU Backwards Mounting
GY-87 mounted backwards due to space constraints. Requires axis correction in software and URDF.

### Square Room SLAM Challenges
Identical walls give SLAM little to work with for loop closure. Always add asymmetric landmarks in square rooms.

### Pico BOOTSEL Reset
Firmware crash requires manual BOOTSEL reset procedure. This cannot be avoided when developing firmware.

---

## 18. Future Work

- **Coverage path planning** — systematic room coverage with `nav2_coverage`
- **Trash/object detection** — YOLO-based detection of objects on the floor
- **Robot arm** — simple manipulator for object interaction
- **ArUco markers** — fiducial markers for reliable relocalization
- **Custom PCB** — replace breadboard with soldered PCB
- **Battery monitoring** — low battery detection and return-to-dock
- **Improved PID** — feedforward term for faster velocity tracking
- **3D mapping** — depth camera upgrade for full 3D environment

---

## 19. Resources

### Learning

| Resource | Link |
|---|---|
| Digikey ROS 2 Tutorial Series | https://www.youtube.com/watch?v=mjrxf8EFSb8&list=PLEBQazB0HUySWueUF2zNyrA8LSX3rDvE7 |
| Camera Module 3 on Ubuntu 24.04 | https://dev.to/minindu_pasan_8f0e03c1063/how-to-setup-raspberry-pi-camera-module-3-on-ubuntu-2404-4pme |
| Nav2 Documentation | https://docs.nav2.org |
| SLAM Toolbox | https://github.com/SteveMacenski/slam_toolbox |
| robot_localization | https://docs.ros.org/en/jazzy/p/robot_localization/ |
| REP-103 coordinate conventions | https://www.ros.org/reps/rep-0103.html |

### Key Packages

| Package | Repository |
|---|---|
| camera_ros | https://github.com/christianrauch/camera_ros |
| rplidar_ros | https://github.com/Slamtec/rplidar_ros |
| slam_toolbox | https://github.com/SteveMacenski/slam_toolbox |
| robot_localization | https://github.com/cra-ros-pkg/robot_localization |
| navigation2 | https://github.com/ros-navigation/navigation2 |
| foxglove_bridge | https://github.com/foxglove/ros-foxglove-bridge |
| SparkFun TB6612FNG | https://github.com/sparkfun/SparkFun_TB6612FNG_Arduino_Library |
| Adafruit MPU6050 | https://github.com/adafruit/Adafruit_MPU6050 |
| libcamera RPi fork | https://github.com/raspberrypi/libcamera |

### Hardware References

| Component | Link |
|---|---|
| DFRobot TT Motor with Encoder | https://www.dfrobot.com/product-1457.html |
| SparkFun TB6612FNG | https://www.sparkfun.com/products/14450 |
| Raspberry Pi 5 | https://datasheets.raspberrypi.com/rpi5/raspberry-pi-5-product-brief.pdf |
| Raspberry Pi Pico 2W | https://datasheets.raspberrypi.com/picow/pico-2-w-datasheet.pdf |
| RPLIDAR A1M8 | https://www.slamtec.ai/wp-content/uploads/2023/11/LD108_SLAMTEC_rplidar_datasheet_A1M8_v3.0_en.pdf |

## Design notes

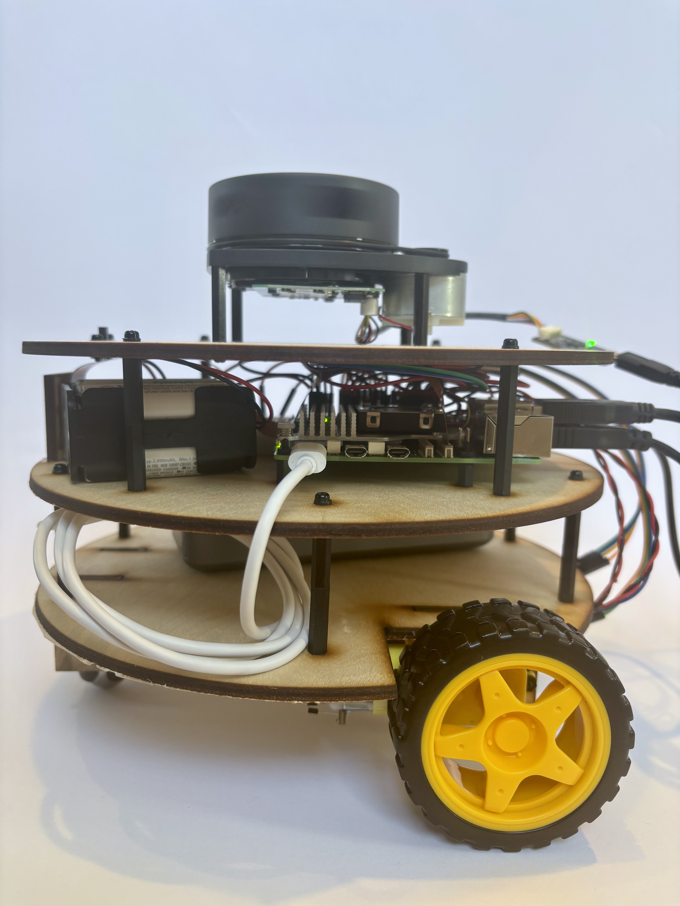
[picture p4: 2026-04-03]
media/robot_side.jpeg

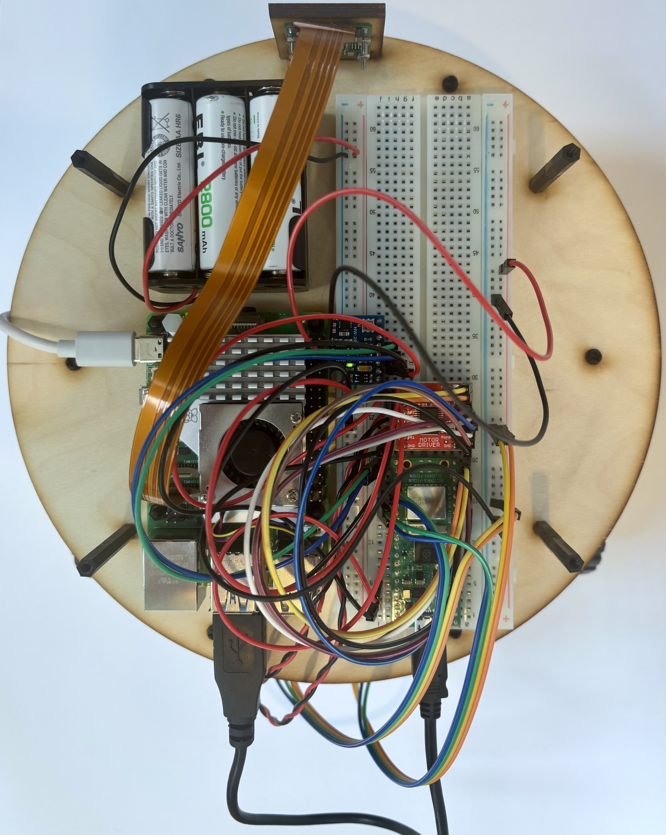
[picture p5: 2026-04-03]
media/robot_top.jpeg

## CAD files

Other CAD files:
cad/chassis.dxf

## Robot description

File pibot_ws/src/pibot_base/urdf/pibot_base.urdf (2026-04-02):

<?xml version="1.0"?>
<!--
  pibot_base.urdf — revised with precise laser-cut measurements
  All values in metres. REP-103 convention: x=forward, y=left, z=up
  Origin (base_link) is at ground level, centre of robot footprint.

  Platform stack (z = centre of each platform disc):
    bottom_platform : z = 0.0507  (wheel_radius 32.5 + 16.2 clearance + 2 half-thickness)
    mid_platform    : z = 0.0947  (bottom_top 52.7 + 40 gap + 2)
    top_platform    : z = 0.1387  (mid_top    96.7 + 40 gap + 2)
    top_platform top: z = 0.1407

  Lidar body centre  : z = 0.16785  (bottom 140.6 + half 27.25)
  Laser plane        : z = 0.1861   (verified)
-->
<robot name="pibot_base">

  <material name="wood">
    <color rgba="0.82 0.67 0.45 1.0"/>
  </material>
  <material name="dark_grey">
    <color rgba="0.2 0.2 0.2 1.0"/>
  </material>
  <material name="black">
    <color rgba="0.1 0.1 0.1 1.0"/>
  </material>
  <material name="blue">
    <color rgba="0.2 0.4 0.8 1.0"/>
  </material>
  <material name="red">
    <color rgba="0.8 0.1 0.1 1.0"/>
  </material>

  <!-- base_link: robot origin at ground level -->
  <link name="base_link"/>

  <!-- Bottom platform z_centre = 0.0507 -->
  <joint name="base_to_bottom_platform" type="fixed">
    <parent link="base_link"/>
    <child link="bottom_platform"/>
    <origin xyz="0.0 0.0 0.0507" rpy="0 0 0"/>
  </joint>
  <link name="bottom_platform">
    <visual>
      <geometry><cylinder radius="0.105" length="0.004"/></geometry>
      <material name="wood"/>
    </visual>
    <collision>
      <geometry><cylinder radius="0.105" length="0.004"/></geometry>
    </collision>
    <inertial>
      <mass value="0.15"/>
      <inertia ixx="0.0004" ixy="0" ixz="0" iyy="0.0004" iyz="0" izz="0.0008"/>
    </inertial>
  </link>

  <!-- Middle platform z_centre = 0.0947 -->
  <joint name="base_to_mid_platform" type="fixed">
    <parent link="base_link"/>
    <child link="mid_platform"/>
    <origin xyz="0.0 0.0 0.0947" rpy="0 0 0"/>
  </joint>
  <link name="mid_platform">
    <visual>
      <geometry><cylinder radius="0.105" length="0.004"/></geometry>
      <material name="wood"/>
    </visual>
    <collision>
      <geometry><cylinder radius="0.105" length="0.004"/></geometry>
    </collision>
    <inertial>
      <mass value="0.15"/>
      <inertia ixx="0.0004" ixy="0" ixz="0" iyy="0.0004" iyz="0" izz="0.0008"/>
    </inertial>
  </link>

  <!-- Top platform z_centre = 0.1387 -->
  <joint name="base_to_top_platform" type="fixed">
    <parent link="base_link"/>
    <child link="top_platform"/>
    <origin xyz="0.0 0.0 0.1387" rpy="0 0 0"/>
  </joint>
  <link name="top_platform">
    <visual>
      <geometry><cylinder radius="0.105" length="0.004"/></geometry>
      <material name="wood"/>
    </visual>
    <collision>
      <geometry><cylinder radius="0.105" length="0.004"/></geometry>
    </collision>
    <inertial>
      <mass value="0.15"/>
      <inertia ixx="0.0004" ixy="0" ixz="0" iyy="0.0004" iyz="0" izz="0.0008"/>
    </inertial>
  </link>

  <!-- Left wheel: x=-0.0553, y=+0.0865, z=0.0325 -->
  <joint name="left_wheel_joint" type="continuous">
    <parent link="base_link"/>
    <child link="left_wheel"/>
    <origin xyz="-0.0553 0.0865 0.0325" rpy="0 0 0"/>
    <axis xyz="0 1 0"/>
  </joint>
  <link name="left_wheel">
    <visual>
      <origin xyz="0 0 0" rpy="1.5708 0 0"/>
      <geometry><cylinder radius="0.0325" length="0.026"/></geometry>
      <material name="dark_grey"/>
    </visual>
    <collision>
      <origin xyz="0 0 0" rpy="1.5708 0 0"/>
      <geometry><cylinder radius="0.0325" length="0.026"/></geometry>
    </collision>
    <inertial>
      <mass value="0.05"/>
      <inertia ixx="0.00002" ixy="0" ixz="0" iyy="0.00002" iyz="0" izz="0.00004"/>
    </inertial>
  </link>

  <!-- Right wheel: x=-0.0553, y=-0.0865, z=0.0325 -->
  <joint name="right_wheel_joint" type="continuous">
    <parent link="base_link"/>
    <child link="right_wheel"/>
    <origin xyz="-0.0553 -0.0865 0.0325" rpy="0 0 0"/>
    <axis xyz="0 1 0"/>
  </joint>
  <link name="right_wheel">
    <visual>
      <origin xyz="0 0 0" rpy="1.5708 0 0"/>
      <geometry><cylinder radius="0.0325" length="0.026"/></geometry>
      <material name="dark_grey"/>
    </visual>
    <collision>
      <origin xyz="0 0 0" rpy="1.5708 0 0"/>
      <geometry><cylinder radius="0.0325" length="0.026"/></geometry>
    </collision>
    <inertial>
      <mass value="0.05"/>
      <inertia ixx="0.00002" ixy="0" ixz="0" iyy="0.00002" iyz="0" izz="0.00004"/>
    </inertial>
  </link>

  <!-- Ball caster: contact 0.8mm above ground, ball centre z=0.010325 -->
  <joint name="ball_caster_joint" type="fixed">
    <parent link="base_link"/>
    <child link="ball_caster"/>
    <origin xyz="0.0868 0.0 0.010325" rpy="0 0 0"/>
  </joint>
  <link name="ball_caster">
    <visual>
      <geometry><sphere radius="0.009525"/></geometry>
      <material name="black"/>
    </visual>
    <collision>
      <geometry><sphere radius="0.009525"/></geometry>
    </collision>
    <inertial>
      <mass value="0.01"/>
      <inertia ixx="0.0000001" ixy="0" ixz="0" iyy="0.0000001" iyz="0" izz="0.0000001"/>
    </inertial>
  </link>

  <!-- Lidar: body centre z=0.16785, laser plane z=0.1861 -->
  <joint name="lidar_joint" type="fixed">
    <parent link="base_link"/>
    <child link="lidar_link"/>
    <origin xyz="0.0069 0.0 0.16785" rpy="0 0 3.14159"/>
  </joint>
  <link name="lidar_link">
    <visual>
      <geometry><cylinder radius="0.035" length="0.0545"/></geometry>
      <material name="blue"/>
    </visual>
    <collision>
      <geometry><cylinder radius="0.035" length="0.0545"/></geometry>
    </collision>
    <inertial>
      <mass value="0.085"/>
      <inertia ixx="0.00003" ixy="0" ixz="0" iyy="0.00003" iyz="0" izz="0.00006"/>
    </inertial>
  </link>

  <!-- Camera lens centre: x=+0.100, y=0.0, z=0.1151 -->
  <joint name="camera_joint" type="fixed">
    <parent link="base_link"/>
    <child link="camera_link"/>
    <origin xyz="0.100 0.0 0.1151" rpy="0 0 0"/>
  </joint>
  <link name="camera_link">
    <visual>
      <geometry><box size="0.0081 0.025 0.025"/></geometry>
      <material name="black"/>
    </visual>
    <collision>
      <geometry><box size="0.0081 0.025 0.025"/></geometry>
    </collision>
    <inertial>
      <mass value="0.003"/>
      <inertia ixx="0.0000001" ixy="0" ixz="0" iyy="0.0000001" iyz="0" izz="0.0000001"/>
    </inertial>
  </link>

  <!-- IMU (GY-87, mounted backwards yaw=pi): x=+0.004, y=-0.004, z=0.1136 -->
  <joint name="imu_joint" type="fixed">
    <parent link="base_link"/>
    <child link="imu_link"/>
    <origin xyz="0.004 -0.004 0.1136" rpy="0 0 3.14159"/>
  </joint>
  <link name="imu_link">
    <visual>
      <geometry><box size="0.02 0.016 0.002"/></geometry>
      <material name="red"/>
    </visual>
    <collision>
      <geometry><box size="0.02 0.016 0.002"/></geometry>
    </collision>
    <inertial>
      <mass value="0.003"/>
      <inertia ixx="0.0000001" ixy="0" ixz="0" iyy="0.0000001" iyz="0" izz="0.0000001"/>
    </inertial>
  </link>

</robot>

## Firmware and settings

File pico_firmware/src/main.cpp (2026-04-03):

#include <Arduino.h>
#include <SparkFun_TB6612.h>
#include <Wire.h>
#include <Adafruit_MPU6050.h>
#include <Adafruit_Sensor.h>

#define DEBUG 0

#define PWMB 9
#define BIN2 10
#define BIN1 11  // right
#define STBY 12
#define AIN1 13  // left
#define AIN2 14
#define PWMA 15

#define MPU_SDA 16
#define MPU_SCL 17

#define ENC_LEFT_A  18
#define ENC_LEFT_B  19
#define ENC_RIGHT_A 20
#define ENC_RIGHT_B 21

const float WHEEL_DIAMETER_M = 0.065f;
const float TICKS_PER_REV    = 2140.0f;
const float DIST_PER_TICK    = PI * WHEEL_DIAMETER_M / TICKS_PER_REV;
const float MAX_WHEEL_VEL    = (160.0f / 60.0f) * PI * WHEEL_DIAMETER_M;

const unsigned long PID_INTERVAL_MS  = 10;   // 100 Hz
const unsigned long SEND_INTERVAL_MS = 20;   // 50 Hz

float KP =  1.5f;
float KI =  0.8f;
float KD =  0.05f;

const int offsetA = -1;
const int offsetB = -1;
const int MIN_PWM =  30;

Motor leftMotor  = Motor(AIN1, AIN2, PWMA, offsetA, STBY);
Motor rightMotor = Motor(BIN1, BIN2, PWMB, offsetB, STBY);

volatile long left_ticks  = 0;
volatile long right_ticks = 0;
int last_l_dir = 1;
int last_r_dir = 1;

void leftEncoderISR()  { left_ticks  += last_l_dir; }
void rightEncoderISR() { right_ticks += last_r_dir; }

float left_integral    = 0.0f;
float left_prev_error  = 0.0f;
float right_integral   = 0.0f;
float right_prev_error = 0.0f;

// Max integral clamp in ticks units — prevents windup
const float MAX_INTEGRAL = 50.0f;

float computePID(float target_ticks, float actual_ticks,
                 float &integral, float &prev_error) {
    float error  = target_ticks - actual_ticks;
    integral    += error;
    integral     = constrain(integral, -MAX_INTEGRAL, MAX_INTEGRAL);
    float deriv  = error - prev_error;
    prev_error   = error;
    return KP * error + KI * integral + KD * deriv;
}

float target_left_vel  = 0.0f;
float target_right_vel = 0.0f;

const int MAX_CHARS = 64;
char input_buf[MAX_CHARS];
int  buf_idx = 0;

Adafruit_MPU6050 mpu;

unsigned long last_pid_time  = 0;
unsigned long last_send_time = 0;

void applyMotor(Motor &motor, int &last_dir,
                float target_vel, float pwm_output,
                float &integral, float &prev_error) {
    if (abs(target_vel) < 1e-4f) {
        last_dir   = 1;
        integral   = 0.0f;
        prev_error = 0.0f;
        motor.drive(0);
        return;
    }

    int direction = target_vel > 0.0f ? 1 : -1;

    if (direction != last_dir) {
        integral   = 0.0f;
        prev_error = 0.0f;
    }
    last_dir = direction;

    int pwm = (int)constrain(abs(pwm_output), 0.0f, 255.0f);
    if (pwm > 0 && pwm < MIN_PWM) pwm = MIN_PWM;
    motor.drive(pwm * direction);
}

void setup() {
    Serial.begin(115200);

    pinMode(ENC_LEFT_A,  INPUT_PULLUP);
    pinMode(ENC_LEFT_B,  INPUT_PULLUP);
    pinMode(ENC_RIGHT_A, INPUT_PULLUP);
    pinMode(ENC_RIGHT_B, INPUT_PULLUP);
    attachInterrupt(digitalPinToInterrupt(ENC_LEFT_A),  leftEncoderISR,  CHANGE);
    attachInterrupt(digitalPinToInterrupt(ENC_RIGHT_A), rightEncoderISR, CHANGE);

    Wire.setSDA(MPU_SDA);
    Wire.setSCL(MPU_SCL);
    Wire.begin();
    if (!mpu.begin(0x68, &Wire)) {
        pinMode(25, OUTPUT);
        while (1) {
            digitalWrite(25, HIGH); delay(200);
            digitalWrite(25, LOW);  delay(200);
        }
    }
    mpu.setAccelerometerRange(MPU6050_RANGE_4_G);
    mpu.setGyroRange(MPU6050_RANGE_500_DEG);
    mpu.setFilterBandwidth(MPU6050_BAND_21_HZ);

    last_pid_time  = millis();
    last_send_time = millis();
}

void loop() {
    while (Serial.available() > 0) {
        char c = Serial.read();
        if (c == '\n') {
            input_buf[buf_idx] = '\0';
            buf_idx = 0;
            char* token = strtok(input_buf, ",");
            if (token != NULL) {
                float lv = atof(token);
                token = strtok(NULL, ",");
                if (token != NULL) {
                    float rv = atof(token);
                    if (abs(lv) <= MAX_WHEEL_VEL * 1.1f &&
                        abs(rv) <= MAX_WHEEL_VEL * 1.1f) {
                        target_left_vel  = lv;
                        target_right_vel = rv;
                    }
                }
            }
        } else if (c != '\r' && buf_idx < MAX_CHARS - 1) {
            input_buf[buf_idx++] = c;
        }
    }

    unsigned long now = millis();
    if (now - last_pid_time >= PID_INTERVAL_MS) {
        last_pid_time = now;

        noInterrupts();
        long lt   = left_ticks;
        long rt   = right_ticks;
        float tlv = target_left_vel;
        float trv = target_right_vel;
        interrupts();

        // Ticks counted since last PID interval
        static long prev_lt = 0;
        static long prev_rt = 0;
        float actual_left_ticks  = (float)(lt - prev_lt);
        float actual_right_ticks = (float)(rt - prev_rt);
        prev_lt = lt;
        prev_rt = rt;

        // Convert m/s target to ticks per interval
        float target_left_ticks  = tlv * (PID_INTERVAL_MS / 1000.0f) / DIST_PER_TICK;
        float target_right_ticks = trv * (PID_INTERVAL_MS / 1000.0f) / DIST_PER_TICK;

        float left_pwm  = computePID(target_left_ticks,  actual_left_ticks,
                                     left_integral,  left_prev_error);
        float right_pwm = computePID(target_right_ticks, actual_right_ticks,
                                     right_integral, right_prev_error);

        applyMotor(leftMotor,  last_l_dir, tlv, left_pwm,
                   left_integral,  left_prev_error);
        applyMotor(rightMotor, last_r_dir, trv, right_pwm,
                   right_integral, right_prev_error);

#if DEBUG
        Serial.print("L tgt:"); Serial.print(target_left_ticks, 2);
        Serial.print(" act:"); Serial.print(actual_left_ticks, 2);
        Serial.print(" pwm:"); Serial.print(left_pwm, 1);
        Serial.print(" | R tgt:"); Serial.print(target_right_ticks, 2);
        Serial.print(" act:"); Serial.print(actual_right_ticks, 2);
        Serial.print(" pwm:"); Serial.println(right_pwm, 1);
#endif
    }

    now = millis();
    if (now - last_send_time >= SEND_INTERVAL_MS) {
        last_send_time = now;

        sensors_event_t a, g, temp;
        mpu.getEvent(&a, &g, &temp);

        noInterrupts();
        long lt = left_ticks;
        long rt = right_ticks;
        interrupts();

#if !DEBUG
        Serial.print(lt);                  Serial.print(",");
        Serial.print(rt);                  Serial.print(",");
        Serial.print(a.acceleration.x, 4); Serial.print(",");
        Serial.print(a.acceleration.y, 4); Serial.print(",");
        Serial.print(a.acceleration.z, 4); Serial.print(",");
        Serial.print(g.gyro.x, 4);         Serial.print(",");
        Serial.print(g.gyro.y, 4);         Serial.print(",");
        Serial.println(g.gyro.z, 4);
#endif
    }
}

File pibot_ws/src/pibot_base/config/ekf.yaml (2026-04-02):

### robot_localization EKF configuration for the Roomba robot
#
# Fuses:
#   /odom         — wheel encoder odometry  (nav_msgs/Odometry)
#   /imu/data_raw — GY-87 MPU6050 IMU       (sensor_msgs/Imu)
#
# Output: /odometry/filtered  (nav_msgs/Odometry)
#
# State vector: [x, y, z, roll, pitch, yaw, vx, vy, vz, vroll, vpitch, vyaw, ax, ay, az]
#               [0  1  2  3     4      5    6   7   8   9      10      11    12  13  14 ]
#
# Config matrix row order matches state vector above.
# true  = use this value from this sensor
# false = ignore this value from this sensor

ekf_node:
  ros__parameters:

    frequency: 50.0          # Hz — matches Pico output rate
    sensor_timeout: 0.1      # seconds before a sensor is considered stale
    two_d_mode: true         # ground robot — ignore z, roll, pitch
    publish_tf: true         # broadcast odom → base_link TF
    map_frame: map
    odom_frame: odom
    base_link_frame: base_link
    world_frame: odom        # use odom as world frame (no map yet)

    # ----------------------------------------------------------------
    # Odometry source: /odom (encoder-based differential drive)
    # ----------------------------------------------------------------
    odom0: /odom
    odom0_config: [
      true,  true,  false,   # x,     y,     z
      false, false, true,    # roll,  pitch, yaw
      true,  false, false,   # vx,    vy,    vz
      false, false, true,    # vroll, vpitch,vyaw
      false, false, false    # ax,    ay,    az
    ]
    odom0_differential: false   # use absolute pose from odometry
    odom0_relative: false
    odom0_queue_size: 10

    # Odometry covariance override — tune if robot drifts
    # Higher value = less trust in this sensor
    # odom0_pose_rejection_threshold: 5.0
    # odom0_twist_rejection_threshold: 1.0

    # ----------------------------------------------------------------
    # IMU source: /imu/data_raw (MPU6050 gyroscope)
    # We only use angular velocity (gz) from the IMU.
    # Orientation is not provided (orientation_covariance[0] = -1).
    # Acceleration is too noisy on a ground robot to use for position.
    # ----------------------------------------------------------------
    imu0: /imu/data_raw
    imu0_config: [
      false, false, false,   # x,     y,     z
      false, false, false,   # roll,  pitch, yaw      (not provided)
      false, false, false,   # vx,    vy,    vz
      false, false, true,    # vroll, vpitch, vyaw    (gz — primary use)
      false, false, false    # ax,    ay,    az       (too noisy)
    ]
    imu0_differential: false
    imu0_relative: false
    imu0_queue_size: 10
    imu0_remove_gravitational_acceleration: true

    # ----------------------------------------------------------------
    # Process noise covariance (Q matrix)
    # Controls how much uncertainty grows during prediction step.
    # Increase a value if the filter is too slow to respond to motion.
    # Decrease if the output is too noisy.
    # Order: x, y, z, roll, pitch, yaw, vx, vy, vz, vroll, vpitch, vyaw, ax, ay, az
    # ----------------------------------------------------------------
    process_noise_covariance: [
      0.05,  0.0,   0.0,   0.0,   0.0,   0.0,   0.0,   0.0,   0.0,   0.0,   0.0,   0.0,   0.0,   0.0,   0.0,
      0.0,   0.05,  0.0,   0.0,   0.0,   0.0,   0.0,   0.0,   0.0,   0.0,   0.0,   0.0,   0.0,   0.0,   0.0,
      0.0,   0.0,   0.06,  0.0,   0.0,   0.0,   0.0,   0.0,   0.0,   0.0,   0.0,   0.0,   0.0,   0.0,   0.0,
      0.0,   0.0,   0.0,   0.03,  0.0,   0.0,   0.0,   0.0,   0.0,   0.0,   0.0,   0.0,   0.0,   0.0,   0.0,
      0.0,   0.0,   0.0,   0.0,   0.03,  0.0,   0.0,   0.0,   0.0,   0.0,   0.0,   0.0,   0.0,   0.0,   0.0,
      0.0,   0.0,   0.0,   0.0,   0.0,   0.06,  0.0,   0.0,   0.0,   0.0,   0.0,   0.0,   0.0,   0.0,   0.0,
      0.0,   0.0,   0.0,   0.0,   0.0,   0.0,   0.025, 0.0,   0.0,   0.0,   0.0,   0.0,   0.0,   0.0,   0.0,
      0.0,   0.0,   0.0,   0.0,   0.0,   0.0,   0.0,   0.025, 0.0,   0.0,   0.0,   0.0,   0.0,   0.0,   0.0,
      0.0,   0.0,   0.0,   0.0,   0.0,   0.0,   0.0,   0.0,   0.04,  0.0,   0.0,   0.0,   0.0,   0.0,   0.0,
      0.0,   0.0,   0.0,   0.0,   0.0,   0.0,   0.0,   0.0,   0.0,   0.01,  0.0,   0.0,   0.0,   0.0,   0.0,
      0.0,   0.0,   0.0,   0.0,   0.0,   0.0,   0.0,   0.0,   0.0,   0.0,   0.01,  0.0,   0.0,   0.0,   0.0,
      0.0,   0.0,   0.0,   0.0,   0.0,   0.0,   0.0,   0.0,   0.0,   0.0,   0.0,   0.02,  0.0,   0.0,   0.0,
      0.0,   0.0,   0.0,   0.0,   0.0,   0.0,   0.0,   0.0,   0.0,   0.0,   0.0,   0.0,   0.01,  0.0,   0.0,
      0.0,   0.0,   0.0,   0.0,   0.0,   0.0,   0.0,   0.0,   0.0,   0.0,   0.0,   0.0,   0.0,   0.01,  0.0,
      0.0,   0.0,   0.0,   0.0,   0.0,   0.0,   0.0,   0.0,   0.0,   0.0,   0.0,   0.0,   0.0,   0.0,   0.015
    ]
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

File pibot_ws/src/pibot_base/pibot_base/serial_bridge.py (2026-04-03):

import math
import threading

import rclpy
from rclpy.node import Node
from rclpy.time import Time

import serial

from geometry_msgs.msg import TransformStamped, Quaternion, Twist
from nav_msgs.msg import Odometry
from sensor_msgs.msg import Imu
from tf2_ros import TransformBroadcaster

WHEEL_DIAMETER_M  = 0.065
WHEELBASE_M       = 0.159
TICKS_PER_REV     = 2140
DIST_PER_TICK     = math.pi * WHEEL_DIAMETER_M / TICKS_PER_REV

MAX_WHEEL_VEL     = (160.0 / 60.0) * math.pi * WHEEL_DIAMETER_M

# Minimum PWM to overcome motor stiction (0–100 scale)
MIN_SPEED         = 10


def _euler_to_quaternion(roll: float, pitch: float, yaw: float) -> Quaternion:
    """Convert roll/pitch/yaw (rad) to a geometry_msgs Quaternion."""
    cy = math.cos(yaw * 0.5)
    sy = math.sin(yaw * 0.5)
    cp = math.cos(pitch * 0.5)
    sp = math.sin(pitch * 0.5)
    cr = math.cos(roll * 0.5)
    sr = math.sin(roll * 0.5)

    q = Quaternion()
    q.w = cr * cp * cy + sr * sp * sy
    q.x = sr * cp * cy - cr * sp * sy
    q.y = cr * sp * cy + sr * cp * sy
    q.z = cr * cp * sy - sr * sp * cy
    return q


def _vel_to_motor_command(wheel_vel: float):
    """
    Convert a wheel velocity (m/s) to (speed 0-100, direction 1/-1).
    Returns (0, 1) for zero velocity.
    """
    if abs(wheel_vel) < 1e-4:
        return 0, 1

    direction = 1 if wheel_vel > 0 else -1
    # Map absolute velocity to MIN_SPEED–100 range
    speed = abs(wheel_vel) / MAX_WHEEL_VEL * 100.0
    speed = max(MIN_SPEED, min(100, int(speed)))
    return speed, direction


class SerialBridge(Node):
    """
    Reads Pico sensor data, publishes /odom and /imu/data_raw,
    and subscribes to /cmd_vel to drive the motors.
    """

    def __init__(self):
        super().__init__('serial_bridge')

        self.declare_parameter('serial_port', '/dev/ttyACM0')
        self.declare_parameter('baud_rate', 115200)
        self.declare_parameter('timeout', 1.0)

        port    = self.get_parameter('serial_port').get_parameter_value().string_value
        baud    = self.get_parameter('baud_rate').get_parameter_value().integer_value
        timeout = self.get_parameter('timeout').get_parameter_value().double_value

        self._odom_pub       = self.create_publisher(Odometry, '/odom', 10)
        self._imu_pub        = self.create_publisher(Imu, '/imu/data_raw', 10)
        self._tf_broadcaster = TransformBroadcaster(self)

        self._cmd_vel_sub = self.create_subscription(
            Twist,
            '/cmd_vel',
            self._cmd_vel_callback,
            10,
        )

        self._x           = 0.0
        self._y           = 0.0
        self._theta       = 0.0
        self._prev_left   = None
        self._prev_right  = None
        self._prev_stamp  = None

        try:
            self._ser = serial.Serial(port, baud, timeout=timeout)
            self.get_logger().info(f'Opened serial port {port} at {baud} baud')
        except serial.SerialException as exc:
            self.get_logger().fatal(f'Cannot open serial port {port}: {exc}')
            raise SystemExit(1)

        self._serial_lock = threading.Lock()

        self._stop_event = threading.Event()
        self._thread = threading.Thread(target=self._read_loop, daemon=True)
        self._thread.start()

        self.get_logger().info('Serial bridge ready — listening on /cmd_vel')

    def _cmd_vel_callback(self, msg: Twist):
        linear  = msg.linear.x
        angular = msg.angular.z

        angular = max(-1.0, min(1.0, angular))
        linear  = max(-MAX_WHEEL_VEL, min(MAX_WHEEL_VEL, linear))

        left_vel  = linear - (angular * WHEELBASE_M / 2.0)
        right_vel = linear + (angular * WHEELBASE_M / 2.0)

        left_vel  = max(-MAX_WHEEL_VEL, min(MAX_WHEEL_VEL, left_vel))
        right_vel = max(-MAX_WHEEL_VEL, min(MAX_WHEEL_VEL, right_vel))

        self._send_motor_command(left_vel, right_vel)

    def _send_motor_command(self, left_vel: float, right_vel: float):
        command = f'{left_vel:.4f},{right_vel:.4f}\n'
        try:
            with self._serial_lock:
                self._ser.write(command.encode())
                self._ser.flush()
        except serial.SerialException as exc:
            self.get_logger().error(f'Serial write error: {exc}')

    def _read_loop(self):
        while not self._stop_event.is_set():
            try:
                with self._serial_lock:
                    raw = self._ser.readline()
            except serial.SerialException as exc:
                self.get_logger().error(f'Serial read error: {exc}')
                continue

            if not raw:
                continue

            try:
                line = raw.decode('utf-8', errors='ignore').strip()
            except Exception:
                continue

            self._parse_and_publish(line)

    def _parse_and_publish(self, line: str):
        parts = line.split(',')
        if len(parts) != 8:
            return

        try:
            left_ticks  = int(parts[0])
            right_ticks = int(parts[1])
            imu_ax      = float(parts[2])
            imu_ay      = float(parts[3])
            imu_az      = float(parts[4])
            imu_gx      = float(parts[5])
            imu_gy      = float(parts[6])
            imu_gz      = float(parts[7])
        except ValueError:
            return

        now = self.get_clock().now()
        self._publish_imu(now, imu_ax, imu_ay, imu_az, imu_gx, imu_gy, imu_gz)
        self._update_odometry(now, left_ticks, right_ticks)

    def _publish_imu(self, stamp: Time,
                     imu_ax, imu_ay, imu_az,
                     imu_gx, imu_gy, imu_gz):
        # IMU is rotated by 180° around up axis
        msg = Imu()
        msg.header.stamp    = stamp.to_msg()
        msg.header.frame_id = 'imu_link'

        msg.linear_acceleration.x = -imu_ay
        msg.linear_acceleration.y = -imu_ax
        msg.linear_acceleration.z =  imu_az

        msg.angular_velocity.x = -imu_gy
        msg.angular_velocity.y = -imu_gx
        msg.angular_velocity.z =  imu_gz

        msg.orientation_covariance[0] = -1.0

        for i in range(9):
            msg.linear_acceleration_covariance[i] = 0.0
            msg.angular_velocity_covariance[i]    = 0.0

        self._imu_pub.publish(msg)

    def _update_odometry(self, stamp: Time, left_ticks: int, right_ticks: int):
        if self._prev_left is None:
            self._prev_left  = left_ticks
            self._prev_right = right_ticks
            self._prev_stamp = stamp
            return

        d_left  = (left_ticks  - self._prev_left)  * DIST_PER_TICK
        d_right = (right_ticks - self._prev_right) * DIST_PER_TICK
        self._prev_left  = left_ticks
        self._prev_right = right_ticks

        d_s     = (d_left + d_right) / 2.0
        d_theta = (d_right - d_left) / WHEELBASE_M

        self._x     += d_s * math.cos(self._theta + d_theta / 2.0)
        self._y     += d_s * math.sin(self._theta + d_theta / 2.0)
        self._theta += d_theta
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

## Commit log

2026-04-02 Add full ROS 2 workspace, Pico firmware, and project README
    Add the complete pibot project: ROS 2 packages (pibot_base, pibot_pkg,
    ball_follow_interface), Pico PID firmware, submodules for camera_ros and
    libcamera (shallow clone), and comprehensive README documentation.
    [pibot_base.urdf]
2026-04-03 add cad, docs and media files
    [chassis.dxf, wiring_fritzing.fzz]
2026-04-03 Update README: camera optional, fix architecture, add media
    Mark camera_ros and libcamera as optional for the core navigation stack.
    Remove camera node from architecture diagram, fix motor label. Add SLAM
    map and Foxglove Nav2 screenshots to their respective sections.
